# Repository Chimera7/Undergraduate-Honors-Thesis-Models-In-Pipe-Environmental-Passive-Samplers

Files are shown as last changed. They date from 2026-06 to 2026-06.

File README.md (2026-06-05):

# Undergraduate Honors Thesis Models: In-Pipe and Cap Environmental Passive Samplers

**Manuscript Title:** Rapid Detection of High-Risk Pathogens: Development of In-Pipe Environmental Passive Samplers  
**Author:** Felix Leahey  

---

## 🎉 Free to Download!

All models are available for free download as **.F3z** (for Fusion 360) and **STL** for scientific development and further research. Use them, iterate on them, and build something better.

Currently, only marks 7 and 10, the main in-pipe and cap sampler are availible. I will soon update with the rest of the models and include .STEP files as well. 

---

## Overview

This repository documents the full design development of passive wastewater sampler models developed over a two-year period starting January 2024. All models are designed to house **0.45μm mixed cellulose ester (MCE) filter discs** for pathogenic DNA/RNA capture from wastewater.

The development spans two project goals:
- **Mark 1**:Open channel passive sampling as an alternative to conventional auto-samplers
- **Marks 2–10**:In-building, in-pipe sampling for floor-by-floor or wing-by-wing sampling specificity in high-risk facilities

A variety of model architectures were explored to address real-world pipe access constraints, culminating in the TPU rubber ring-integrated **Mark 7** and the T-intersection cleanout lid models **Marks 8 through 10**.

---

## Design Generations

### Mark 1
The base model, conceived January 2024. The filter is placed between two slotted plates and slid into the confines of the "U"-shaped body. The lid can only be removed in the direction opposite to running water and solids, ensuring it cannot be dislodged by flow. This safety principle was carried forward into all subsequent generations.

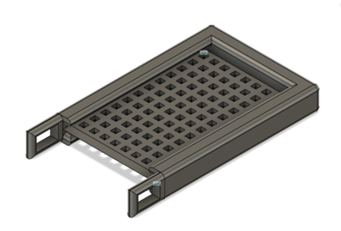
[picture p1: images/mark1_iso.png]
Mark 1 ISO view

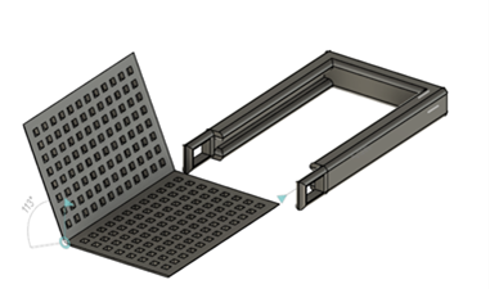
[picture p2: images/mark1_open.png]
Mark 1 open plates


---

### Mark 2
With the inception of the in-pipe sampling goal, Mark 2 rounded out the flat and boxy Mark 1 frame with a thin, easy-to-slide lid. However, the internal space was still too large and did not adequately restrain the filter paper, allowing movement inside the sampler body.

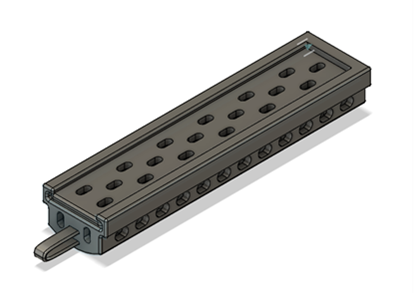
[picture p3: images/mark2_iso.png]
Mark 2 ISO view

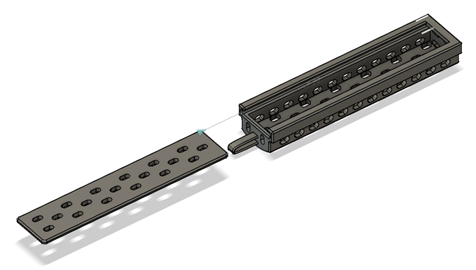
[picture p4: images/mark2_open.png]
Mark 2 body and lid separated


---

### Mark 3
Mark 3 began approaching the in-pipe design goal in earnest. The model was slimmed and rounded for fitting inside a circular pipe while maintaining the directional lid retention principle from Mark 1.

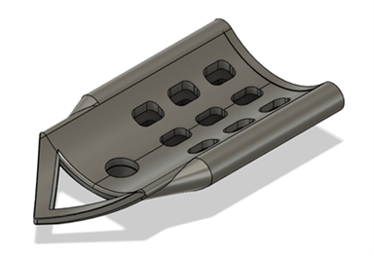
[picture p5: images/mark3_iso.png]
Mark 3 ISO view

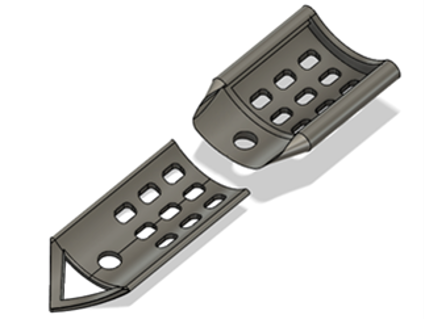
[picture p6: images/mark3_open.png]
Mark 3 lid and body separated


---

### Mark 4
Mark 4 improved on Mark 3 by eliminating the internal cavity so the filter is sandwiched directly between body and lid, as in Mark 1. The slide retention wall height was reduced to facilitate easier lid placement and removal. The two separated handles at the top were identified as a structural weakness, being prone to snapping under stress.

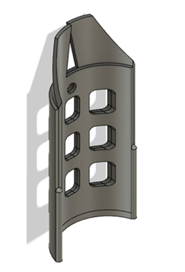
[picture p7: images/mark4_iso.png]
Mark 4 ISO view

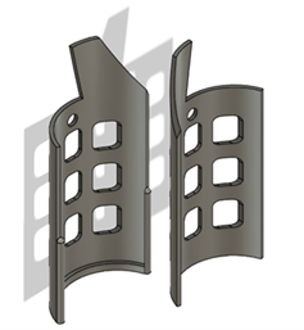
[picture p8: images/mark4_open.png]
Mark 4 body and lid separated


---

### Mark 5
A divergent design option. The sliding lid mechanism combined with the tight filter fit caused filter paper tearing during loading. Mark 5 explored converting to a **snapping lid**, circumventing the risk of dragging and damaging the filter membrane during insertion.

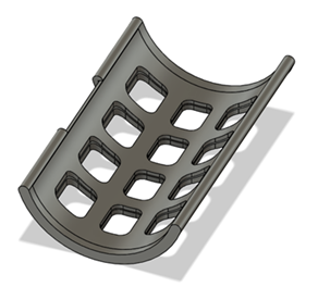
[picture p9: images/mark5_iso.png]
Mark 5 ISO view

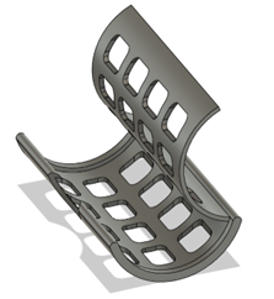
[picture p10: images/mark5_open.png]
Mark 5 body and lid separated


---

### Mark 6
Mark 6 refined the snap-lid design of Mark 5. Wall thickness was increased by several millimeters for resilience, and small plastic orientation rings were added to keep the sampler correctly positioned inside the pipe and prevent it from flipping. This generation also introduced the **filter membrane cavity** — an intentional recess that prevents the lid from dragging across and tearing the filter during loading or unloading.

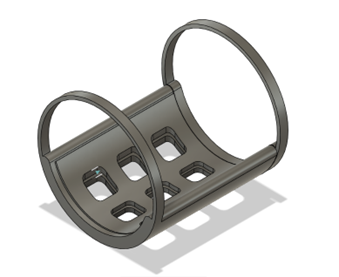
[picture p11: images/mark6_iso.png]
Mark 6 ISO view

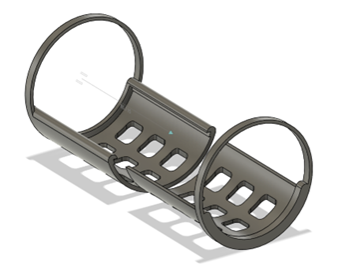
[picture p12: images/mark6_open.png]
Mark 6 body and lid separated

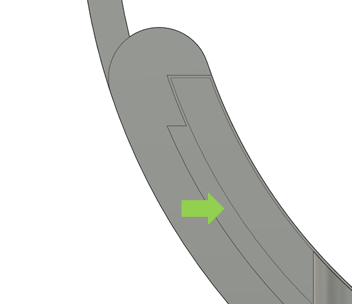
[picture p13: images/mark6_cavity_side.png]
Filter cavity side view

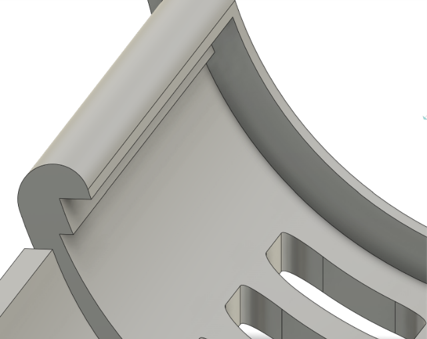
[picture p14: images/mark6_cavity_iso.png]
Filter cavity ISO view


---

### Mark 7
Mark 7 integrated separately printed **TPU rubber rings**, providing the flexibility to navigate imperfect pipe entry conditions — most notably a sharp 90-degree insertion angle. This model was the **first to be fully parameterized**, allowing it to be adapted to a range of pipe diameters faster and more easily than any prior generation.

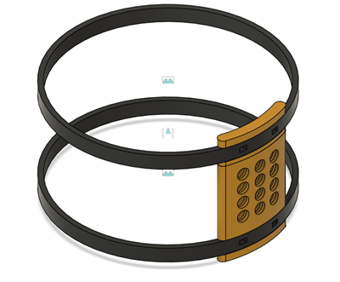
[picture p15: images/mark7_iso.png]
Mark 7 ISO view

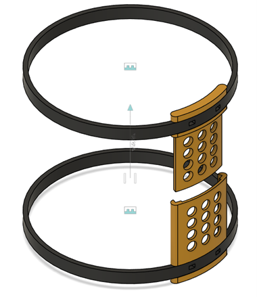
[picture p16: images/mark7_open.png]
Mark 7 lid and body separated


---

### Mark 8
The first **"cap" sampler**, designed to affix to a T-intersection plumbing cleanout cap. The sampler body mounts on threaded bolts with washers and nuts, and printed spacers position it at the correct depth to sit flush with the intersecting pipe at the T-junction.

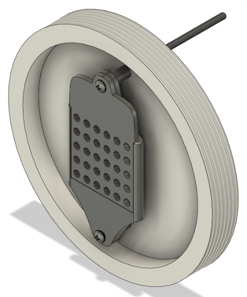
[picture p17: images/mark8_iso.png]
Mark 8 ISO view

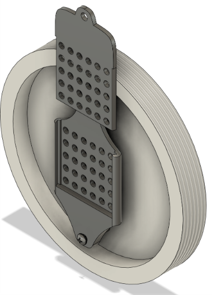
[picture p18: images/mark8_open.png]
Mark 8 body, lid, and cap separated


---

### Mark 9
A full redesign of the cap sampler format for **4" diameter caps**, in contrast to Mark 8's 6" diameter. This was necessitated after a prospective test hospital confirmed their pipe access points were 4" upon arrival — contrary to the originally communicated 6".

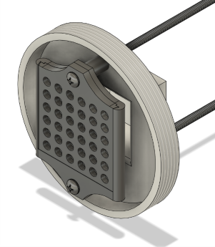
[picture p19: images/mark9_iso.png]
Mark 9 ISO view

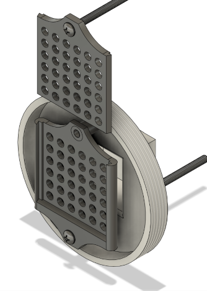
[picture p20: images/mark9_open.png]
Mark 9 lid separated


---

### Mark 9 (B)
An iteration on Mark 9 featuring elongated screw holes in the linear direction, allowing a longer spacer on one end to tilt the sampler at an angle once installed. The intention was to have the sampler protrude into the pipe flow to maximize wastewater exposure. Quickly succeeded by Mark 10.

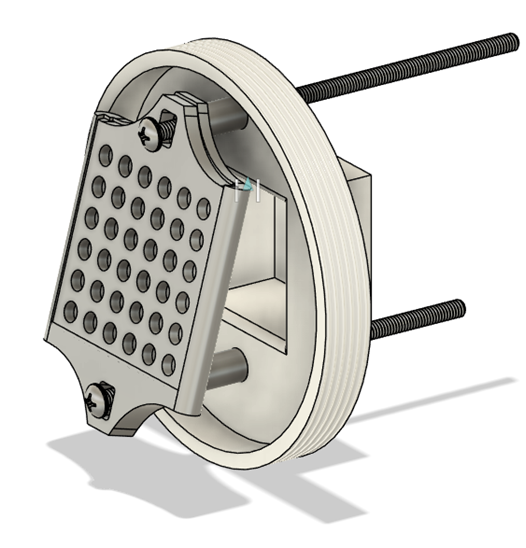
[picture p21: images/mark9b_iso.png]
Mark 9B ISO view


---

### Mark 10
The current most refined cap sampler. Mark 10 introduces a **curvature on the sampler body face** that matches the profile of the intersecting pipe as closely as possible, minimizing solids aggregation on the sampler surface. The model is designed to sit flush within the T-intersection cleanout when fully installed.

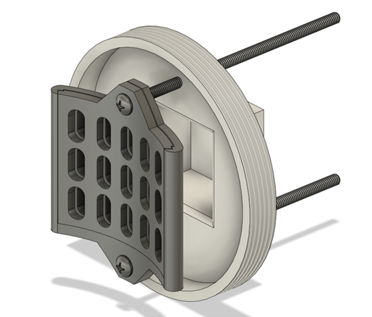
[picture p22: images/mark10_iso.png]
Mark 10 ISO view

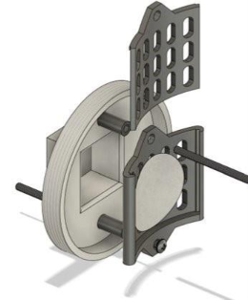
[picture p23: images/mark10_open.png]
Mark 10 lid separated

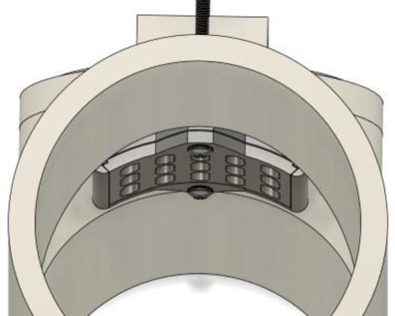
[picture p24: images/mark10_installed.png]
Mark 10 in T-intersection cleanout

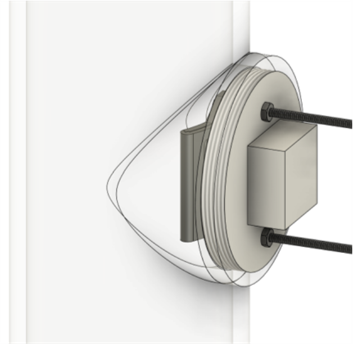
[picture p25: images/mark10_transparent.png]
Mark 10 transparent T-intersection view


---

## Citation

If you use these models in your research, please cite:

> Leahey, F. (2026). *Rapid Detection of High-Risk Pathogens: Development of In-Pipe Environmental Passive Samplers* [Undergraduate Honors Thesis]. Oregon State University.

---

## Contact

For questions about the models or methodology, feel free to open an issue on this repository.

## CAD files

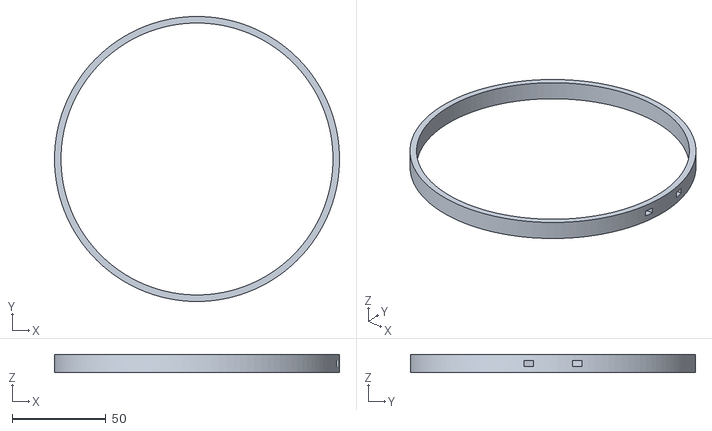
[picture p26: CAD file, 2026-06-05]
3D-Models/Mark 7 TPU Ring (STL).stl
152.4 x 152.4 x 9.85

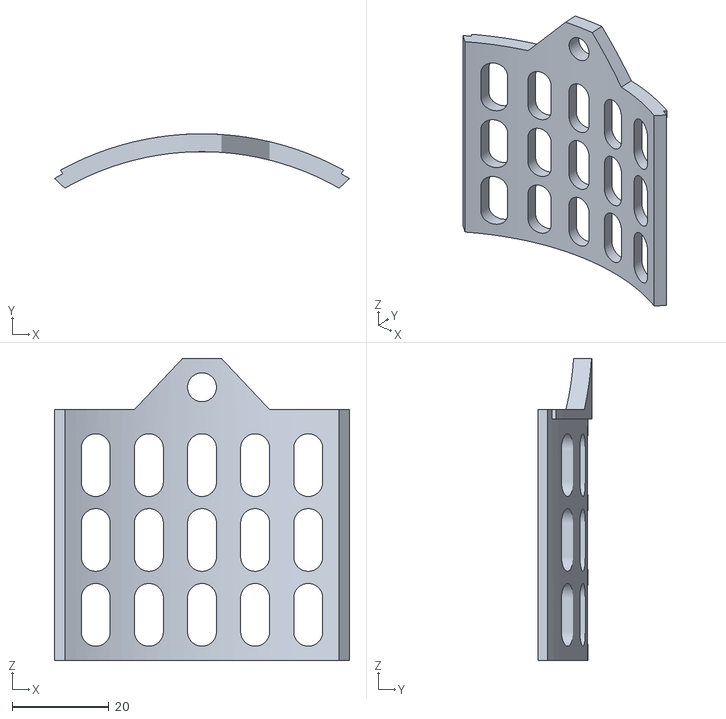
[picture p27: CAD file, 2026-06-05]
3D-Models/Mark 10 Part 2 (STL).stl
61.1 x 11.3 x 62.6

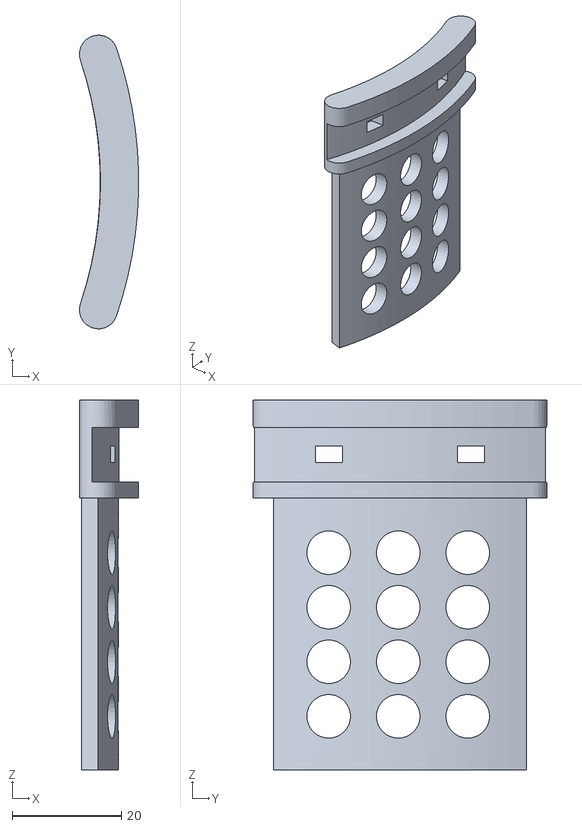
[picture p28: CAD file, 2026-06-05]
3D-Models/Mark 7 Part 2 (STL).stl
10.8 x 53.9 x 67.9

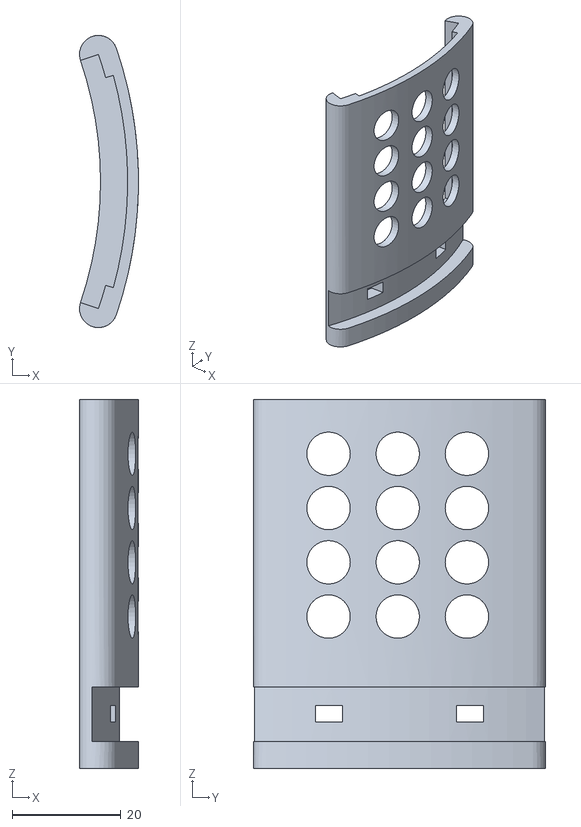
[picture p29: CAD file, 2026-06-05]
3D-Models/Mark 7 Part 1 STL.stl
10.9 x 53.9 x 68.0

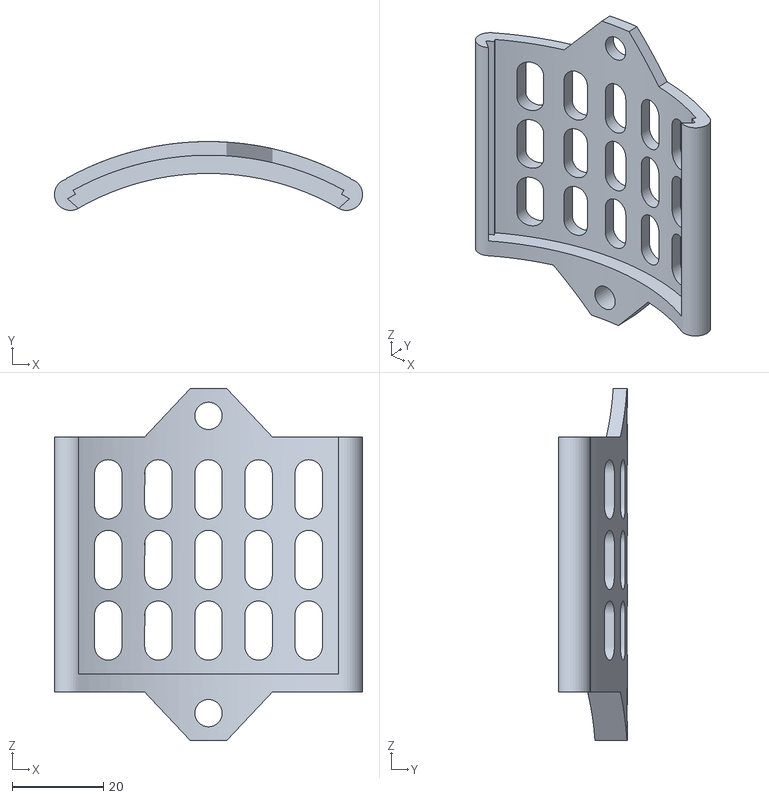
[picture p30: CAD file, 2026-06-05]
3D-Models/Mark 10 Part 1 (STL).stl
67.6 x 15.1 x 77.2

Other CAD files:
3D-Models/Mark 10 (Fusion).f3d
3D-Models/Mark 7 (Fusion).f3d

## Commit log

2026-06-05 Create placeholder.txt
    Explanation of each sampler generation with associated images
2026-06-05 Add files via upload
    Here are the two most important models. I will update this with the rest sooon
    [Mark 10 (Fusion).f3d, Mark 10 Part 1 (STL).stl, Mark 10 Part 2 (STL).stl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]
